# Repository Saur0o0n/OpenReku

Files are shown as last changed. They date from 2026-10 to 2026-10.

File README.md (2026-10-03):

<picture>
  <source media="(prefers-color-scheme: dark)" srcset=".github/images/openreku-logo-white.svg">
  OpenReku
</picture>

Otwarty projekt sterownika rekuperatora opartego na ESP32 i ESPHome, współpracującego z Home Assistant. Obejmuje elektronikę sterownika oraz konfigurację obsługującą wentylatory, zawory i czujniki.

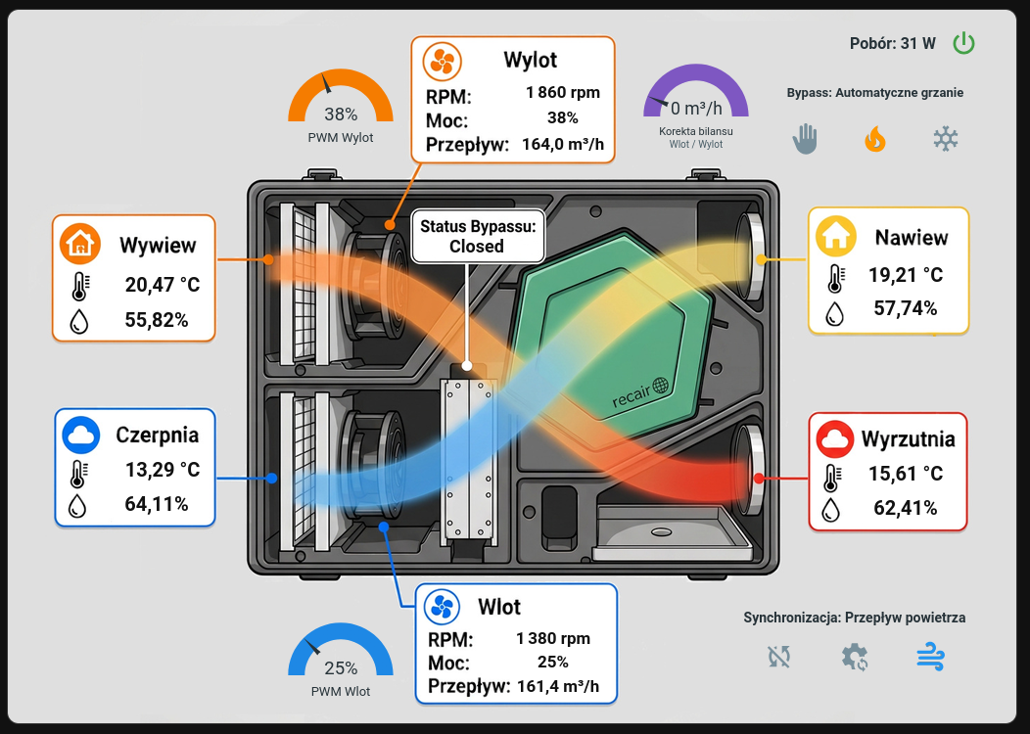
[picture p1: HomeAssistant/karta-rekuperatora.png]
OpenReku — sterowanie rekuperatorem w Home Assistant


## Zawartość repozytorium

| Katalog | Zawartość |
| --- | --- |
| [PCB/](PCB/) | Projekt płytki w wersji 1.1: schematy i PCB KiCad, lokalne biblioteki, lista elementów BOM, Gerbery do produkcji. |
| [ESPHome/](ESPHome/) | Konfiguracja `rekuperator.yaml` z obsługą urządzenia i integracją z Home Assistant oraz wzór `secrets.yaml.example` do uzupełnienia własnymi danymi dostępowymi. |
| [HomeAssistant/](HomeAssistant/) | Karta panelu Home Assistant, automatyzacje testu filtrów i korekty bilansu oraz podkład graficzny karty. |

Opis plików i instrukcję otwarcia projektu elektroniki zawiera [PCB/README.md](PCB/README.md). Przygotowanie konfiguracji i pliku sekretów opisano w [ESPHome/README.md](ESPHome/README.md). Sposób dodania karty do panelu opisano w [HomeAssistant/README.md](HomeAssistant/README.md).

## Licencja

Projekt PCB, dokumentacja i własne grafiki są udostępnione na licencji [CC BY-NC 4.0](LICENSES/CC-BY-NC-4.0.txt), a kod i konfiguracje YAML ESPHome oraz Home Assistant — na [PolyForm Noncommercial 1.0.0](LICENSES/PolyForm-Noncommercial-1.0.0.txt).

Możesz je kopiować, modyfikować i udostępniać do celów niekomercyjnych, na warunkach odpowiedniej licencji. Przy udostępnianiu zachowaj informację o autorze **Sauron**, nazwie **OpenReku**, [źródle projektu](https://github.com/Saur0o0n/OpenReku) i licencji; dla materiałów CC BY-NC oznacz również wprowadzone zmiany. Kod zawiera obowiązkową informację `Required Notice:`.

Zakres licencji i wyłączenia dotyczące cudzych materiałów określa [LICENSE](LICENSE). Wykorzystanie komercyjne wykraczające poza udzielone licencje wymaga osobnej zgody właścicieli praw.

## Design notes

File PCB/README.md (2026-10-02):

# OpenReku — PCB 1.1

Projekt płytki sterownika rekuperatora OpenReku, rewizja **1.1 z 2026-10-01**. Ten katalog zawiera źródła KiCada, lokalne biblioteki, listę elementów i archiwum produkcyjne PCB. Oprogramowanie ESPHome i pozostałe komponenty projektu należą do osobnych katalogów repozytorium.

## Wizualizacja PCB

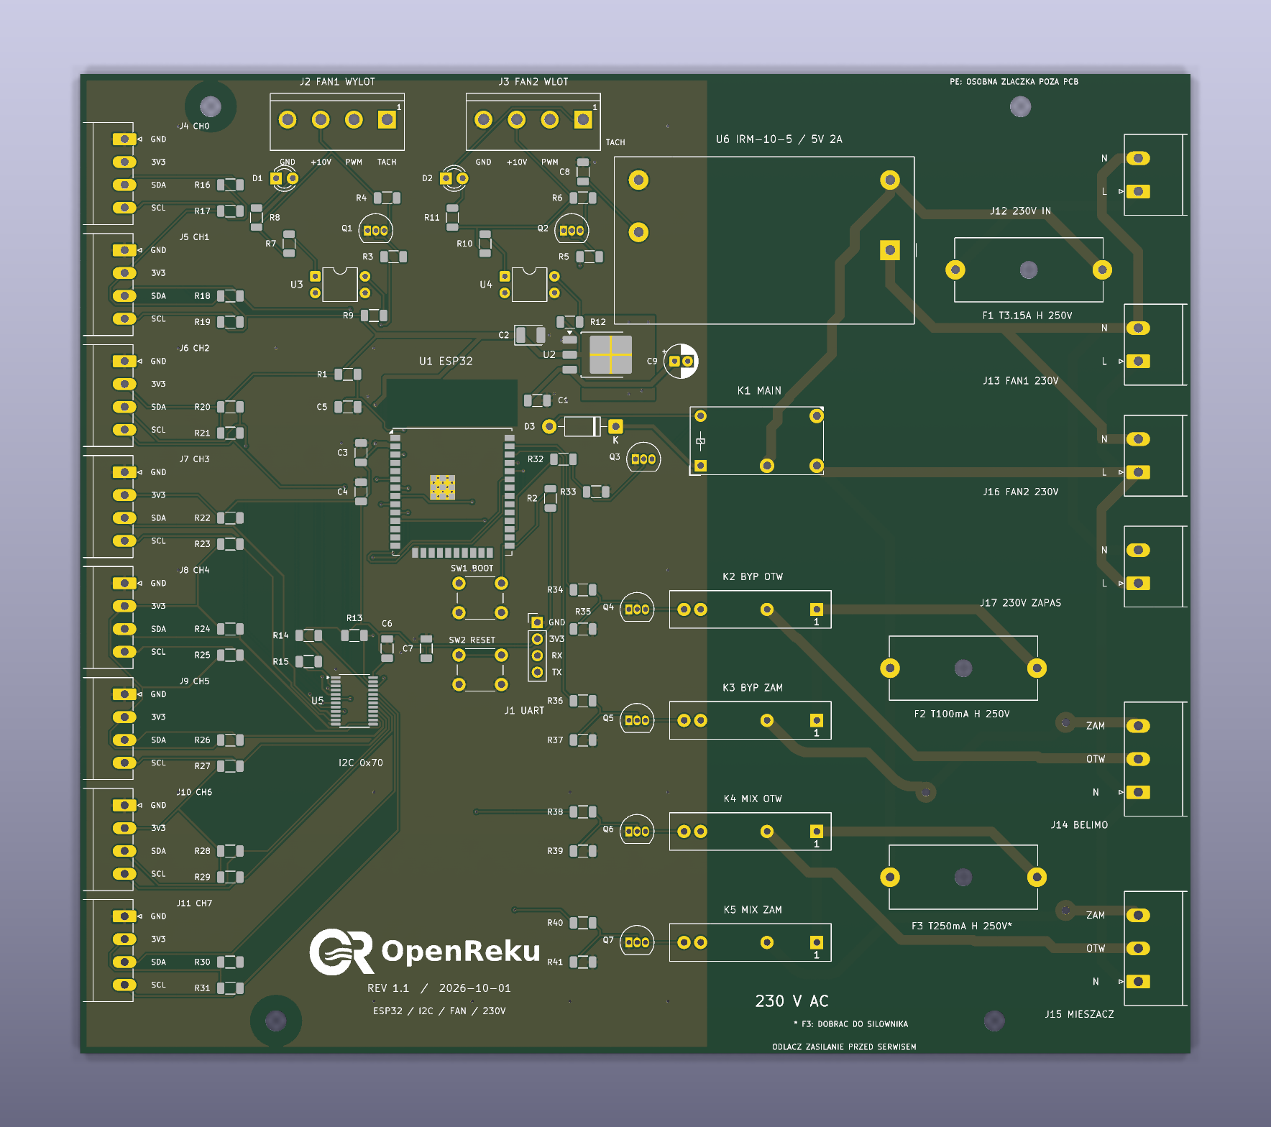
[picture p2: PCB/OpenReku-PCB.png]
OpenReku PCB 1.1 — widok płytki od góry


## Otwieranie projektu

Otwórz [OpenReku.kicad_pro](OpenReku.kicad_pro) w **KiCad 10**. Potrzebne są standardowe biblioteki symboli, footprintów i — do podglądu 3D — modeli KiCad 10.

Zachowaj razem wszystkie pliki z tego katalogu i podkatalog `Rekuperator.pretty`. KiCad odnajduje lokalne biblioteki względem katalogu, w którym znajduje się `OpenReku.kicad_pro`. Dzięki temu projekt można sklonować do dowolnego miejsca na komputerze.

Tabele `fp-lib-table` i `sym-lib-table` korzystają ze zmiennej `${KIPRJMOD}`, którą KiCad rozwija do katalogu projektu.

Lokalne biblioteki mają nazwę `Rekuperator`, używaną w odwołaniach schematu i PCB.

## Zawartość katalogu

| Plik lub katalog | Typ i przeznaczenie |
| --- | --- |
| [OpenReku.kicad_pro](OpenReku.kicad_pro) | Projekt KiCad: wspólne ustawienia schematu i PCB, klasy sieci oraz konfiguracja kontroli projektu. Główny plik do otwarcia. |
| [OpenReku.kicad_sch](OpenReku.kicad_sch) | Główny schemat KiCad: mikrokontroler, zasilanie części logicznej, interfejsy wentylatorów i odwołania do arkuszy podrzędnych. |
| [I2C.kicad_sch](I2C.kicad_sch) | Podrzędny arkusz schematu: multiplekser I²C i złącza czujników. Otwieraj w kontekście głównego projektu. |
| [230V.kicad_sch](230V.kicad_sch) | Podrzędny arkusz schematu: zasilanie sieciowe, zabezpieczenia, przekaźniki i wyjścia 230 V. |
| [OpenReku.kicad_pcb](OpenReku.kicad_pcb) | Projekt PCB KiCad: obrys płytki, rozmieszczenie elementów, ścieżki, przelotki, wylewki miedzi i nadruki. |
| [OpenReku.kicad_dru](OpenReku.kicad_dru) | Własne reguły DRC KiCada, w tym wymagane odstępy między częścią sieciową i niskonapięciową. |
| [Rekuperator.kicad_sym](Rekuperator.kicad_sym) | Lokalna biblioteka symboli schematowych KiCad; zawiera symbol przekaźnika SSR G3MB-202P. |
| [sym-lib-table](sym-lib-table) | Tabela bibliotek symboli projektu: rejestruje lokalną bibliotekę `Rekuperator.kicad_sym`. |
| [Rekuperator.pretty/](Rekuperator.pretty/) | Lokalna biblioteka footprintów KiCad. Każdy plik `.kicad_mod` opisuje pola lutownicze, obrysy lub grafikę jednego footprintu. Szczegóły poniżej. |
| [fp-lib-table](fp-lib-table) | Tabela bibliotek footprintów projektu: rejestruje katalog `Rekuperator.pretty`. |
| [BOM.csv](BOM.csv) | Lista elementów wersji 1.1, wyeksportowana z całej hierarchii schematu. Format CSV UTF-8, separator przecinek. |
| [OpenReku-v1.1-Gerber.zip](OpenReku-v1.1-Gerber.zip) | Archiwum do wykonania samej PCB: Gerbery obu warstw miedzi, obu soldermasek, górnego nadruku i obrysu, wiercenia PTH/NPTH oraz opis zadania `.gbrjob`. Nie zawiera plików automatycznego montażu. |

### Lokalna biblioteka footprintów

Poniższe pliki znajdują się w `Rekuperator.pretty/`:

| Plik `.kicad_mod` | Przeznaczenie |
| --- | --- |
| `ESP32-WROOM-32U_0.3mm_ThermalDrills.kicad_mod` | Footprint modułu ESP32-WROOM-32U z otworami termicznymi 0,3 mm. |
| `KLS2-EDV-5.08-04P-4_Vertical.kicad_mod` | Czteropinowe złącze interfejsu wentylatora, raster 5,08 mm. |
| `Omron_G3MB-202P_SIP4.kicad_mod` | Footprint przekaźnika SSR Omron G3MB-202P. |
| `PhoenixContact_MC_1,5_4-G-3.5_1x04_P3.50mm_Horizontal_Edge.kicad_mod` | Kątowe, czteropinowe złącze I²C, raster 3,50 mm, z obrysem dopasowanym do montażu przy krawędzi. |
| `PhoenixContact_MSTBA_2,5_2-G-5,08_1x02_P5.08mm_Horizontal_Edge.kicad_mod` | Kątowe, dwupinowe złącze 230 V, raster 5,08 mm, montowane przy krawędzi. |
| `PhoenixContact_MSTBA_2,5_3-G-5,08_1x03_P5.08mm_Horizontal_Edge.kicad_mod` | Kątowe, trzypinowe złącze 230 V, raster 5,08 mm, montowane przy krawędzi. |
| `Logo_OpenReku_36mm.kicad_mod` | Logo OR + OpenReku o szerokości 36 mm na górnej warstwie nadruku; nie jest elementem do zakupu. |

## BOM — lista elementów

`BOM.csv` zawiera **47 grup i 93 elementy**. Grupowanie uwzględnia wartość, footprint, numer części oraz pozostałe eksportowane właściwości, dzięki czemu elementy z odmiennymi uwagami montażowymi pozostają osobnymi pozycjami.

| Kolumna | Znaczenie |
| --- | --- |
| `Reference` | Oznaczenia elementów na schemacie i PCB, np. `R1,R2`. |
| `Quantity` | Liczba elementów w grupie. |
| `Value` | Wartość lub nazwa elementu ze schematu. |
| `Footprint` | Identyfikator biblioteki i footprintu KiCad. |
| `MPN` | Numer części producenta, jeżeli uzupełniono go w schemacie. |
| `MatingConnector` | Opis współpracującego wtyku; wtyk nie jest dodatkowo doliczony do `Quantity`. |
| `Pinout` | Opis wyprowadzeń zapisany w schemacie. |
| `AssemblyNote` | Uwagi montażowe, w tym warunki pominięcia rezystorów podciągających. |
| `DNP` | Oznaczenie elementu przewidzianego do pominięcia przy montażu, jeżeli ustawiono je w KiCadzie. |
| `Datasheet` | Odnośnik do dokumentacji części zapisany w schemacie. |

Puste pole oznacza brak informacji w schemacie. BOM nie obejmuje otworów montażowych H1–H4 ani logo LOGO1. Jest listą elementów projektu; współpracujące wtyki, przewody i osprzęt mechaniczny należy zestawić osobno.

Aby odtworzyć BOM, uruchom w tym katalogu:

```sh
kicad-cli sch export bom \
  --output BOM.csv \
  --fields 'Reference,QUANTITY,Value,Footprint,MPN,MatingConnector,Pinout,AssemblyNote,DNP,Datasheet' \
  --labels 'Reference,Quantity,Value,Footprint,MPN,MatingConnector,Pinout,AssemblyNote,DNP,Datasheet' \
  --group-by 'Value,Footprint,MPN,MatingConnector,Pinout,AssemblyNote,DNP,Datasheet' \
  --sort-field Reference \
  --ref-range-delimiter '' \
  OpenReku.kicad_sch
```

## Rewizja 1.1 względem 1.0

- Obrys PCB zmniejszono z 210 × 180 mm do **170 × 150 mm**.
- Rezystory R1–R41 i kondensatory ceramiczne C1/C3/C4/C5/C6/C7/C8 mają obudowy **1206**. C2 pozostaje tantalowy, a C9 przewlekany.
- Złącza I²C J4–J11 przesunięto o 2 mm w stronę krawędzi, zachowując raster 3,50 mm.
- Złącza 230 V J12–J17 zmieniono z rastra 7,62 mm na **5,08 mm**.
- Przeniesiono C5 i zarezerwowano miejsce dla dłuższego modułu ESP-32S 18 × 25,5 mm. Projekt elektryczny nadal wskazuje ESP32-WROOM-32U; zgodność innego modułu wymaga sprawdzenia jego padów i sposobu podłączenia anteny.
- Zmieniono rozmieszczenie i routing oraz dodano logo OR + OpenReku na górnym nadruku.

Źródła i Gerbery wersji **1.0** są dostępne w historii Git, w commicie `764cad7`. Bieżący katalog zawiera rewizję **1.1**.

## Produkcja PCB

Pliki do wykonania płytki znajdują się w [OpenReku-v1.1-Gerber.zip](OpenReku-v1.1-Gerber.zip). Parametry zamówienia:

- wymiary: **170 × 150 mm**;
- **2 warstwy**, laminat **FR-4 1,6 mm**;
- miedź **35 µm / 1 oz**;
- soldermaska obustronna, nadruk na górze.

Po zmianie projektu PCB należy ponownie wygenerować Gerbery i pliki wierceń.

Reguły DRC określają odstępy 8 mm między częścią sieciową i niskonapięciową oraz 3 mm między różnymi sieciami części sieciowej.

Pliki lokalnych ustawień `*.kicad_prl`, blokady `*.lck`, autosave, kopie zapasowe i cache footprintów są pomijane przez główny [`.gitignore`](../.gitignore). Nie są potrzebne do odtworzenia projektu.

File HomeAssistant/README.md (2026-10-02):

# OpenReku — karta Home Assistant

Karta `picture-elements` z odczytami temperatury i wilgotności, obrotami i przepływem wentylatorów, wskaźnikami PWM oraz sterowaniem bypassem i synchronizacją wentylatorów.

## Pliki

| Plik | Przeznaczenie |
| --- | --- |
| [karta_rekuperator.yaml](karta_rekuperator.yaml) | Konfiguracja karty do wklejenia w edytorze YAML panelu Home Assistant. |
| [automations/test_filtrow.yaml](automations/test_filtrow.yaml) | Automatyzacja uruchamiająca codzienny test filtrów o 03:30. |
| [automations/korekta_bilansu_wyciag.yaml](automations/korekta_bilansu_wyciag.yaml) | Korekta bilansu nawiew/wywiew zależna od stanu wyciągu kuchennego. |
| [www/rekuperator2.jpg](www/rekuperator2.jpg) | Podkład graficzny karty z ilustracją rekuperatora i polami na odczyty. |

## Przykład

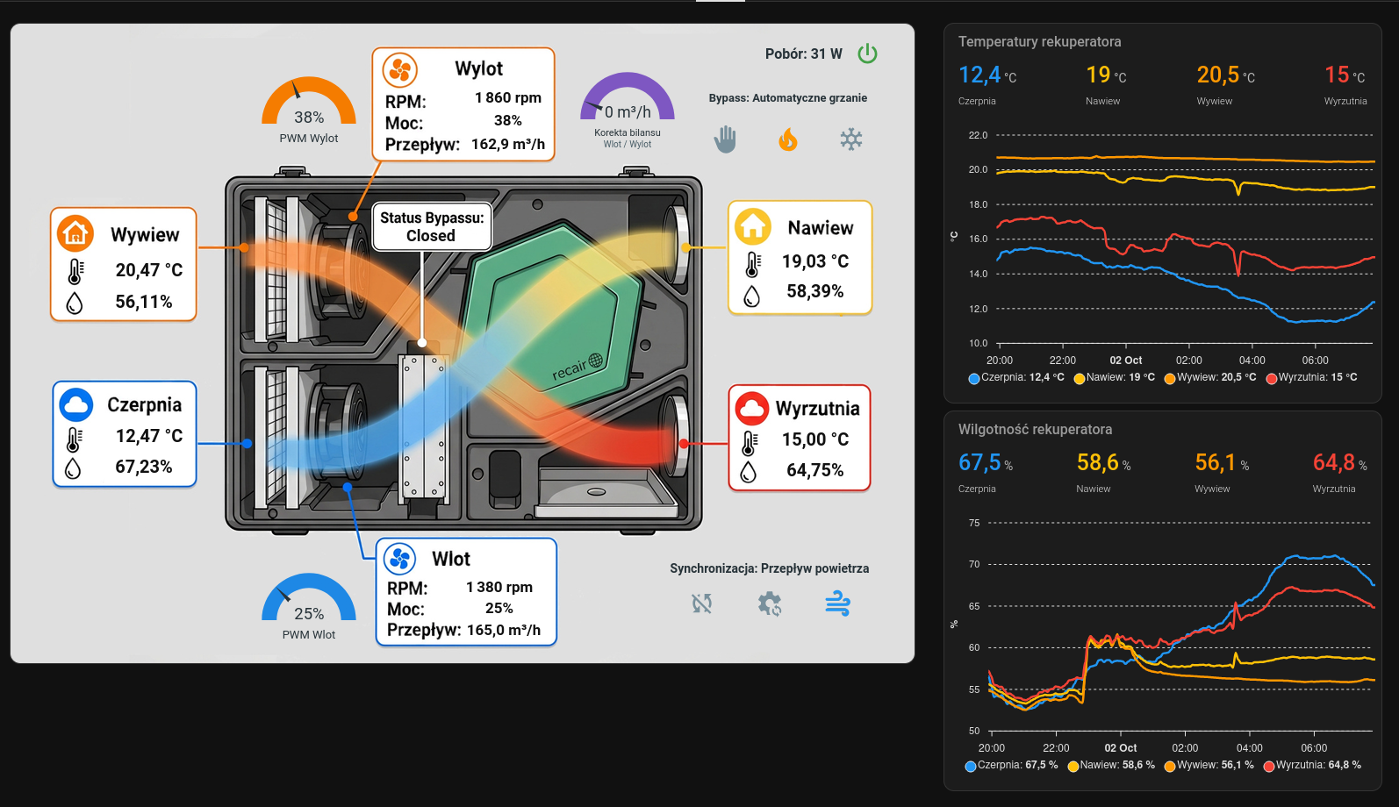
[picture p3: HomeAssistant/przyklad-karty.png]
Karta rekuperatora w Home Assistant


YAML zawiera kartę z ilustracją po lewej stronie. Wykresy temperatur i wilgotności widoczne po prawej są osobnymi kartami panelu.

## Instalacja

1. Dodaj urządzenie ESPHome do Home Assistant, aby udostępnić jego encje.
2. Zainstaluj dodatki [hui-element](https://github.com/thomasloven/lovelace-hui-element) i [Gauge Card Pro](https://github.com/benjamin-dcs/gauge-card-pro), np. przez HACS, zgodnie z ich instrukcjami. Karta używa `custom:hui-element` do osadzania wskaźników `custom:gauge-card-pro` i komunikatu trybu serwisowego.
3. Skopiuj `www/rekuperator2.jpg` do katalogu `www` konfiguracji Home Assistant, zwykle `/config/www/rekuperator2.jpg`. W YAML odpowiada mu ścieżka `image: /local/rekuperator2.jpg`. Jeśli tworzysz katalog `www` po raz pierwszy, uruchom ponownie Home Assistant. [Opis obsługi plików lokalnych](https://www.home-assistant.io/integrations/http/#hosting-files).
4. W edycji panelu dodaj kartę ręczną i wklej zawartość `karta_rekuperator.yaml`.
5. Dopasuj identyfikatory encji do swojej instalacji. Plik używa nazw z prefiksem `kotlownia_rekuperator_`; mogą się one różnić od nazw utworzonych przez Twoją integrację ESPHome.

## Test filtrów

W edytorze automatyzacji Home Assistant utwórz nową automatyzację i wklej w trybie YAML zawartość [test_filtrow.yaml](automations/test_filtrow.yaml). Godzina `03:30:00` odnosi się do strefy czasowej Home Assistanta.

Automatyzacja wywołuje `esphome.rekuperator_run_filter_test`. Jeśli urządzenie ma inną nazwę, wybierz odpowiadającą mu akcję `run_filter_test`. Procedurę pomiarową wykonuje ESPHome.

## Wyciąg kuchenny

Wklej [korekta_bilansu_wyciag.yaml](automations/korekta_bilansu_wyciag.yaml) jako osobną automatyzację w edytorze YAML. Ustawia korektę bilansu na `30` przy włączonym wyciągu i na `0` przy wyłączonym.

Dopasuj encję wyciągu `switch.shelly1pm3_wentylator_switch_0` oraz encję korekty `number.kotlownia_rekuperator_korekta_bilansu_wlot_wylot` do swojej instalacji.

## Encje i obsługa

- Temperatury i wilgotności: czerpnia, nawiew, wywiew i wyrzutnia.
- Wentylatory: PWM, RPM i przepływ powietrza dla wlotu i wylotu.
- Synchronizacja: `Brak`, `Moc PWM` lub `Przepływ powietrza`, wraz z korektą bilansu.
- Bypass: stan zaworu oraz wybór `Ręczne sterowanie`, `Automatyczne grzanie` lub `Automatyczne chłodzenie`.
- Zasilanie i tryb serwisowy: po wyłączeniu zasilania karta jest przygaszona, a sterowanie zablokowane poza przyciskiem zasilania. Tryb serwisowy blokuje całą kartę i wyświetla komunikat.

Odczyt „Pobór” korzysta z osobnego licznika energii: `sensor.kotlownia_shellypmminig3_rekuperator_power`. Podmień tę encję na własny pomiar mocy albo usuń odpowiadający jej element `state-label`, jeśli nie używasz licznika.

Układ nakłada odczyty na konkretne miejsca podkładu. Przy zmianie grafiki zachowaj jej proporcje lub dopasuj pozycje `top` i `left` elementów.

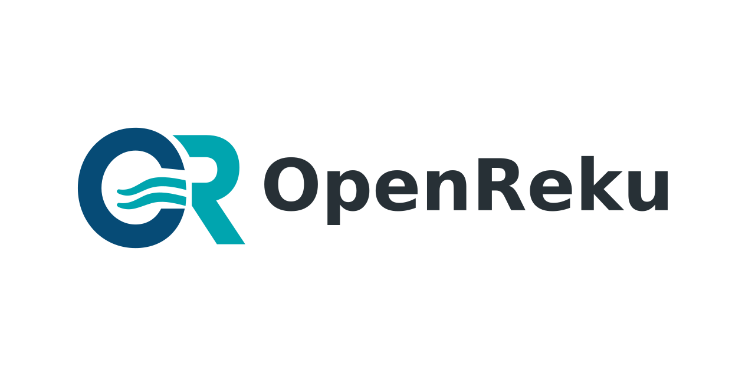
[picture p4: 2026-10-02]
.github/images/social-preview.png

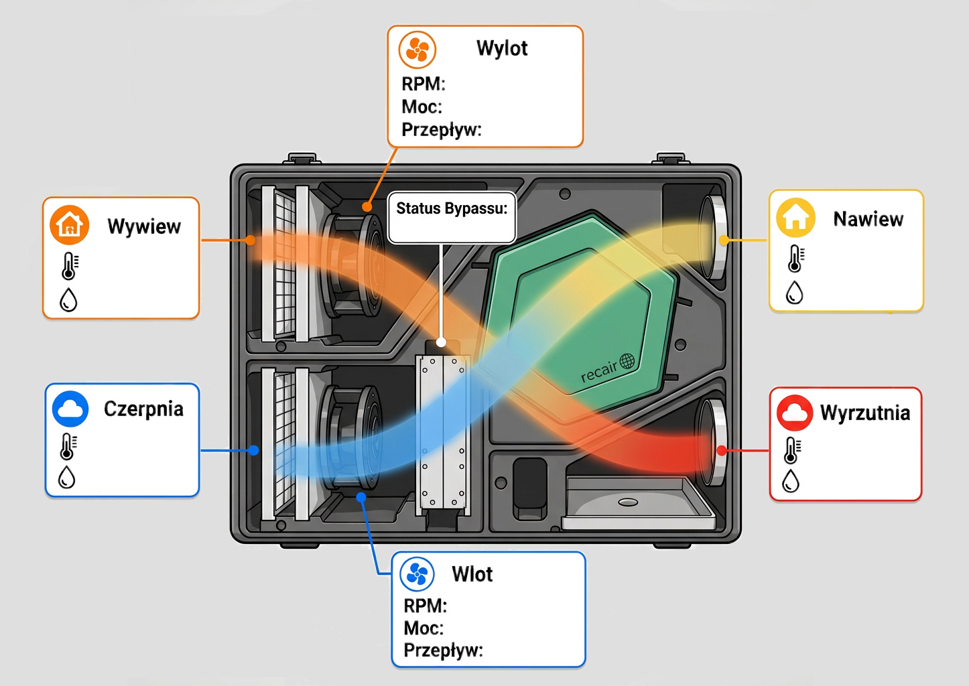
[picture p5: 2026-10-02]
HomeAssistant/www/rekuperator2.jpg

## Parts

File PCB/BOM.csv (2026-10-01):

Reference | Quantity | Value | Footprint | MPN | MatingConnector | Pinout | AssemblyNote | DNP | Datasheet
C1 | 1 | 10uF / 16V X7R | Capacitor_SMD:C_1206_3216Metric
C2 | 1 | 22uF / 10V Ta | Capacitor_Tantalum_SMD:CP_EIA-3528-21_Kemet-B
C3,C6,C8 | 3 | 100nF | Capacitor_SMD:C_1206_3216Metric
C4 | 1 | 10uF | Capacitor_SMD:C_1206_3216Metric
C5 | 1 | 1uF / 10V X7R | Capacitor_SMD:C_1206_3216Metric
C7 | 1 | 1uF | Capacitor_SMD:C_1206_3216Metric
C9 | 1 | 47uF / 16V | Capacitor_THT:CP_Radial_D5.0mm_P2.00mm
D1,D2 | 2 | LED RPM | LED_THT:LED_D3.0mm
D3 | 1 | 1N4007 | Diode_THT:D_DO-41_SOD81_P10.16mm_Horizontal
F1 | 1 | T3.15A H 250V | Fuse:Fuseholder_Cylinder-5x20mm_Schurter_0031_8201_Horizontal_Open
F2 | 1 | T100mA H 250V | Fuse:Fuseholder_Cylinder-5x20mm_Schurter_0031_8201_Horizontal_Open
F3 | 1 | T250mA H 250V * | Fuse:Fuseholder_Cylinder-5x20mm_Schurter_0031_8201_Horizontal_Open
J1 | 1 | UART 3V3 | Connector_PinHeader_2.54mm:PinHeader_1x04_P2.54mm_Vertical
J2 | 1 | FAN1 WYLOT | Rekuperator:KLS2-EDV-5.08-04P-4_Vertical | KLS2-EDV-5.08-04P-4 | KLS2-EDK-5.08-04P-4S |  |  |  | https://img.klsele.com/admin/product_upload/20250331141523L-KLS2-EDV-5.00%265.08.pdf
J3 | 1 | FAN2 WLOT | Rekuperator:KLS2-EDV-5.08-04P-4_Vertical | KLS2-EDV-5.08-04P-4 | KLS2-EDK-5.08-04P-4S |  |  |  | https://img.klsele.com/admin/product_upload/20250331141523L-KLS2-EDV-5.00%265.08.pdf
J4 | 1 | CH0 ARK 3.5 | Rekuperator:PhoenixContact_MC_1,5_4-G-3.5_1x04_P3.50mm_Horizontal_Edge | 1844236 | Phoenix Contact 1840382 / MC 1,5/4-ST-3,5 | 1 GND; 2 +3V3; 3 SDA; 4 SCL
J5 | 1 | CH1 ARK 3.5 | Rekuperator:PhoenixContact_MC_1,5_4-G-3.5_1x04_P3.50mm_Horizontal_Edge | 1844236 | Phoenix Contact 1840382 / MC 1,5/4-ST-3,5 | 1 GND; 2 +3V3; 3 SDA; 4 SCL
J6 | 1 | CH2 ARK 3.5 | Rekuperator:PhoenixContact_MC_1,5_4-G-3.5_1x04_P3.50mm_Horizontal_Edge | 1844236 | Phoenix Contact 1840382 / MC 1,5/4-ST-3,5 | 1 GND; 2 +3V3; 3 SDA; 4 SCL
J7 | 1 | CH3 ARK 3.5 | Rekuperator:PhoenixContact_MC_1,5_4-G-3.5_1x04_P3.50mm_Horizontal_Edge | 1844236 | Phoenix Contact 1840382 / MC 1,5/4-ST-3,5 | 1 GND; 2 +3V3; 3 SDA; 4 SCL
J8 | 1 | CH4 ARK 3.5 | Rekuperator:PhoenixContact_MC_1,5_4-G-3.5_1x04_P3.50mm_Horizontal_Edge | 1844236 | Phoenix Contact 1840382 / MC 1,5/4-ST-3,5 | 1 GND; 2 +3V3; 3 SDA; 4 SCL
J9 | 1 | CH5 ARK 3.5 | Rekuperator:PhoenixContact_MC_1,5_4-G-3.5_1x04_P3.50mm_Horizontal_Edge | 1844236 | Phoenix Contact 1840382 / MC 1,5/4-ST-3,5 | 1 GND; 2 +3V3; 3 SDA; 4 SCL
J10 | 1 | CH6 ARK 3.5 | Rekuperator:PhoenixContact_MC_1,5_4-G-3.5_1x04_P3.50mm_Horizontal_Edge | 1844236 | Phoenix Contact 1840382 / MC 1,5/4-ST-3,5 | 1 GND; 2 +3V3; 3 SDA; 4 SCL
J11 | 1 | CH7 ARK 3.5 | Rekuperator:PhoenixContact_MC_1,5_4-G-3.5_1x04_P3.50mm_Horizontal_Edge | 1844236 | Phoenix Contact 1840382 / MC 1,5/4-ST-3,5 | 1 GND; 2 +3V3; 3 SDA; 4 SCL
J12 | 1 | 230V IN | Rekuperator:PhoenixContact_MSTBA_2,5_2-G-5,08_1x02_P5.08mm_Horizontal_Edge | 1757242 | MSTB 2,5/2-ST-5,08 | 1 MAINS_L_IN; 2 MAINS_N
J13 | 1 | REKU FAN 1 | Rekuperator:PhoenixContact_MSTBA_2,5_2-G-5,08_1x02_P5.08mm_Horizontal_Edge | 1757242 | MSTB 2,5/2-ST-5,08 | 1 MAINS_L_REKU; 2 MAINS_N
J14 | 1 | BELIMO | Rekuperator:PhoenixContact_MSTBA_2,5_3-G-5,08_1x03_P5.08mm_Horizontal_Edge | 1757255 | MSTB 2,5/3-ST-5,08 | 1 MAINS_N; 2 MAINS_BYPASS_OPEN; 3 MAINS_BYPASS_CLOSE
J15 | 1 | MIX 230V | Rekuperator:PhoenixContact_MSTBA_2,5_3-G-5,08_1x03_P5.08mm_Horizontal_Edge | 1757255 | MSTB 2,5/3-ST-5,08 | 1 MAINS_N; 2 MAINS_MIX_OPEN; 3 MAINS_MIX_CLOSE
J16 | 1 | REKU FAN 2 | Rekuperator:PhoenixContact_MSTBA_2,5_2-G-5,08_1x02_P5.08mm_Horizontal_Edge | 1757242 | MSTB 2,5/2-ST-5,08 | 1 MAINS_L_REKU; 2 MAINS_N
J17 | 1 | REKU ZAPAS | Rekuperator:PhoenixContact_MSTBA_2,5_2-G-5,08_1x02_P5.08mm_Horizontal_Edge | 1757242 | MSTB 2,5/2-ST-5,08 | 1 MAINS_L_REKU; 2 MAINS_N
K1 | 1 | Finder 32.21 / 5V | Relay_THT:Relay_SPDT_Finder_32.21-x000 | 32.21.7.005.4000 |  |  | 6 A AC1; verify recuperator inrush and load category before production
K2,K3,K4,K5 | 4 | G3MB-202P DC5 | Rekuperator:Omron_G3MB-202P_SIP4 | G3MB-202P DC5 |  |  | Legacy tested prototype circuit; load current below 100mA is outside manufacturer specification |  | https://components101.com/sites/default/files/component_datasheet/G3MB-202P-Datasheet.pdf
Q1,Q2,Q3,Q4,Q5,Q6,Q7 | 7 | 2N3904 | Package_TO_SOT_THT:TO-92_Inline
R1,R2,R4,R6,R15 | 5 | 10k | Resistor_SMD:R_1206_3216Metric
R3,R5 | 2 | 2.2k | Resistor_SMD:R_1206_3216Metric
R7,R10 | 2 | 1.8k | Resistor_SMD:R_1206_3216Metric
R8,R9,R11,R12,R13,R14 | 6 | 4.7k | Resistor_SMD:R_1206_3216Metric
R16,R17,R18,R19,R20,R21,R22,R23,R24,R25,R26,R27,R28,R29,R30,R31 | 16 | 4.7k | Resistor_SMD:R_1206_3216Metric |  |  |  | Omit if sensor module already has adequate pull-up to 3.3 V
R32 | 1 | 470 | Resistor_SMD:R_1206_3216Metric
R33,R35,R37,R39,R41 | 5 | 100k | Resistor_SMD:R_1206_3216Metric
R34,R36,R38,R40 | 4 | 1k | Resistor_SMD:R_1206_3216Metric
SW1 | 1 | BOOT | Button_Switch_THT:SW_PUSH_6mm
SW2 | 1 | RESET | Button_Switch_THT:SW_PUSH_6mm
U1 | 1 | ESP32-WROOM-32U | Rekuperator:ESP32-WROOM-32U_0.3mm_ThermalDrills |  |  |  |  |  | https://www.espressif.com/sites/default/files/documentation/esp32-wroom-32d_esp32-wroom-32u_datasheet_en.pdf
U2 | 1 | LM1117DT-3.3 | Package_TO_SOT_SMD:TO-252-3_TabPin2 |  |  |  |  |  | http://www.ti.com/lit/ds/symlink/lm1117.pdf
U3,U4 | 2 | PC817 | Package_DIP:DIP-4_W7.62mm
U5 | 1 | TCA9548APWR | Package_SO:TSSOP-24_4.4x7.8mm_P0.65mm | TCA9548APWR |  |  |  |  | https://www.ti.com/lit/ds/symlink/tca9548a.pdf
U6 | 1 | IRM-10-5 | Converter_ACDC:Converter_ACDC_MeanWell_IRM-10-xx_THT

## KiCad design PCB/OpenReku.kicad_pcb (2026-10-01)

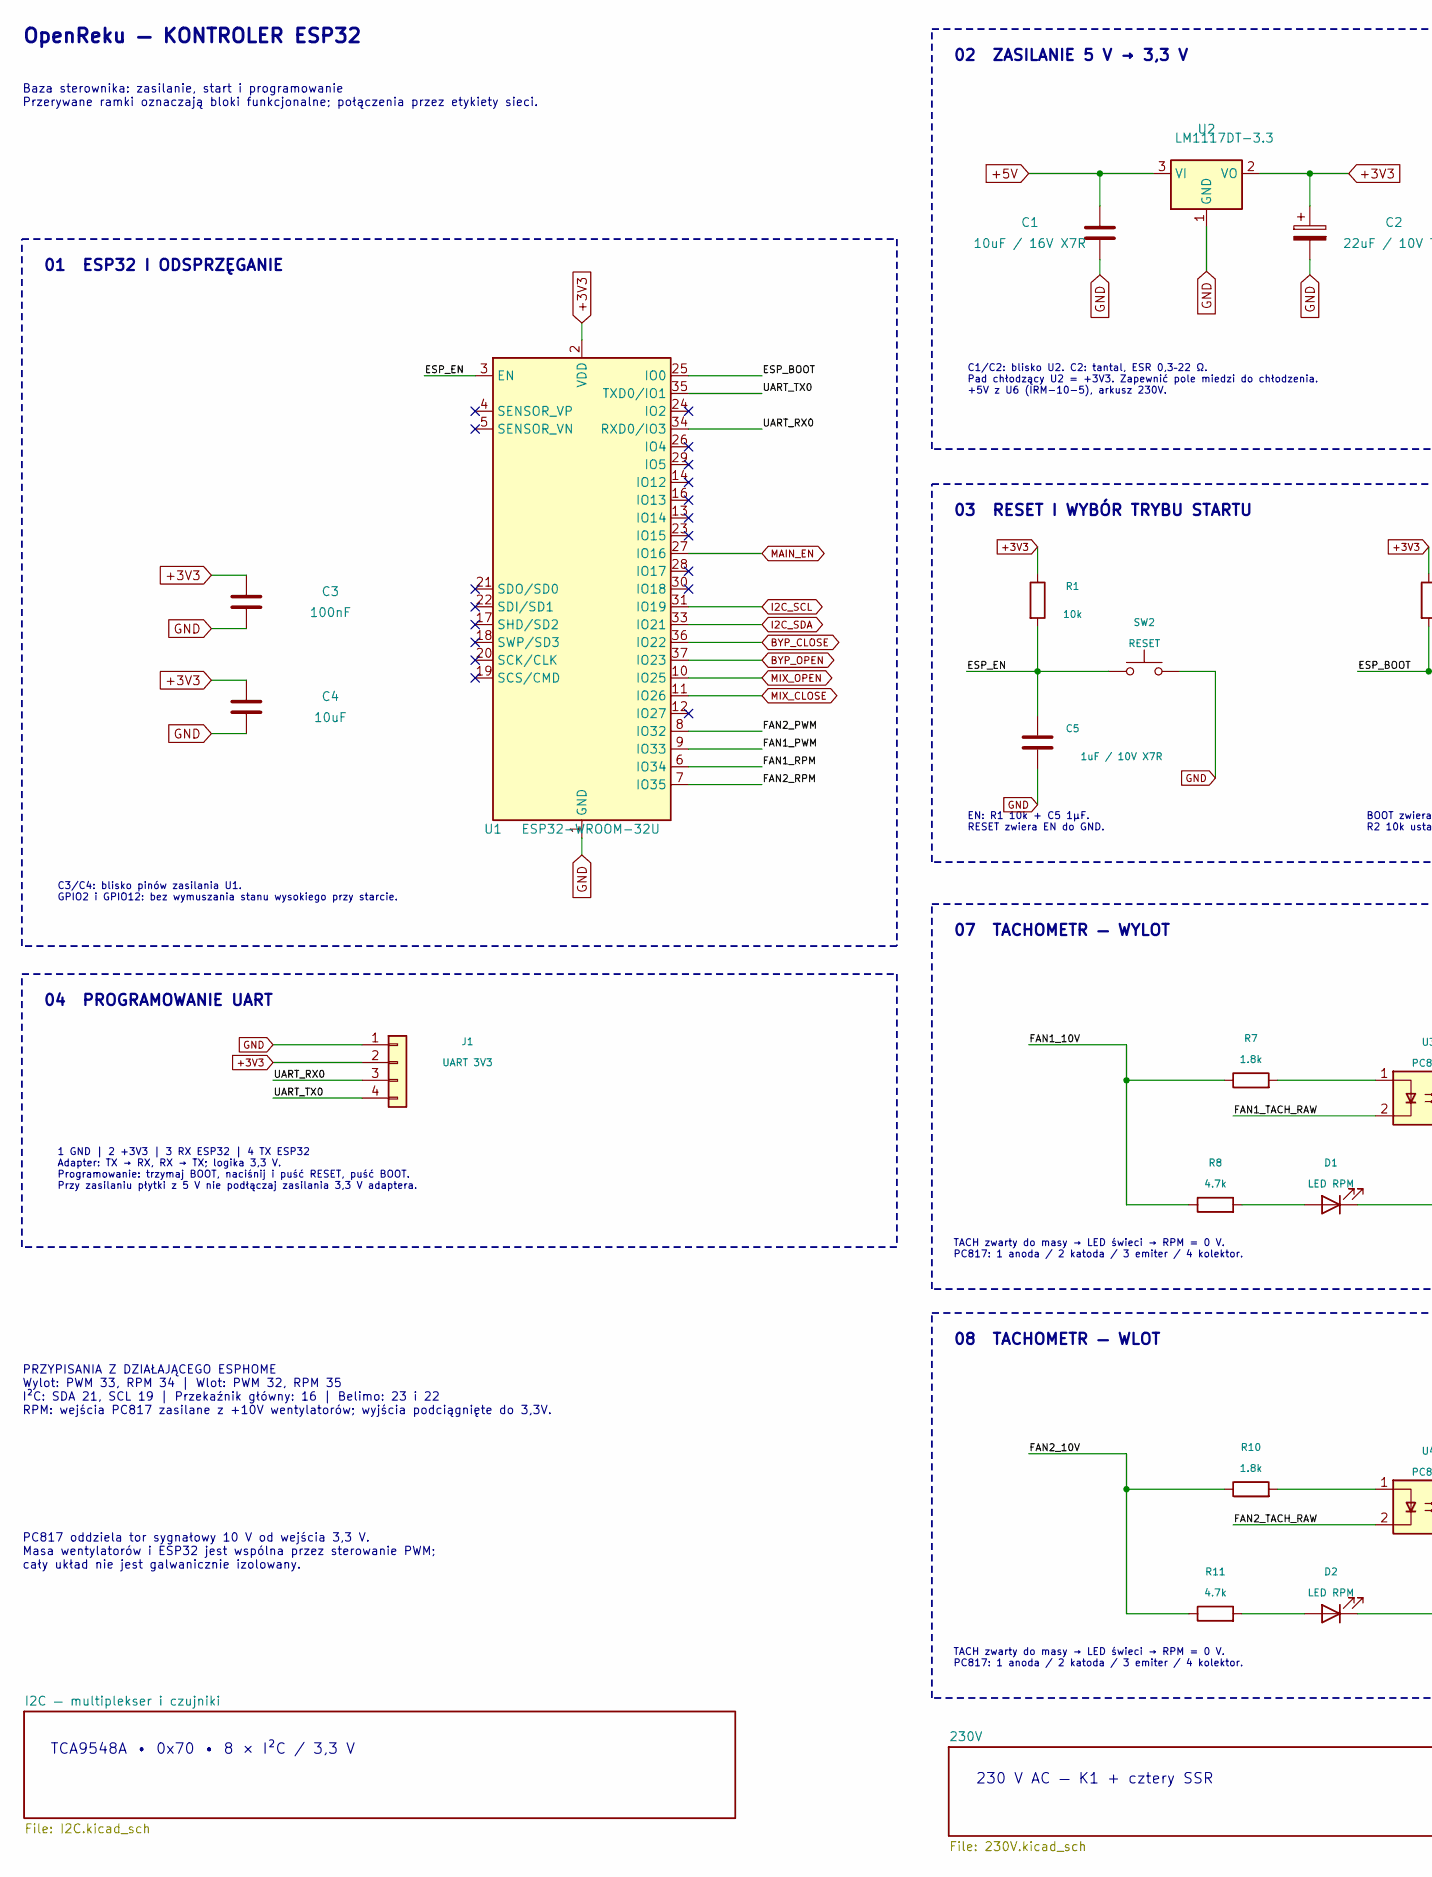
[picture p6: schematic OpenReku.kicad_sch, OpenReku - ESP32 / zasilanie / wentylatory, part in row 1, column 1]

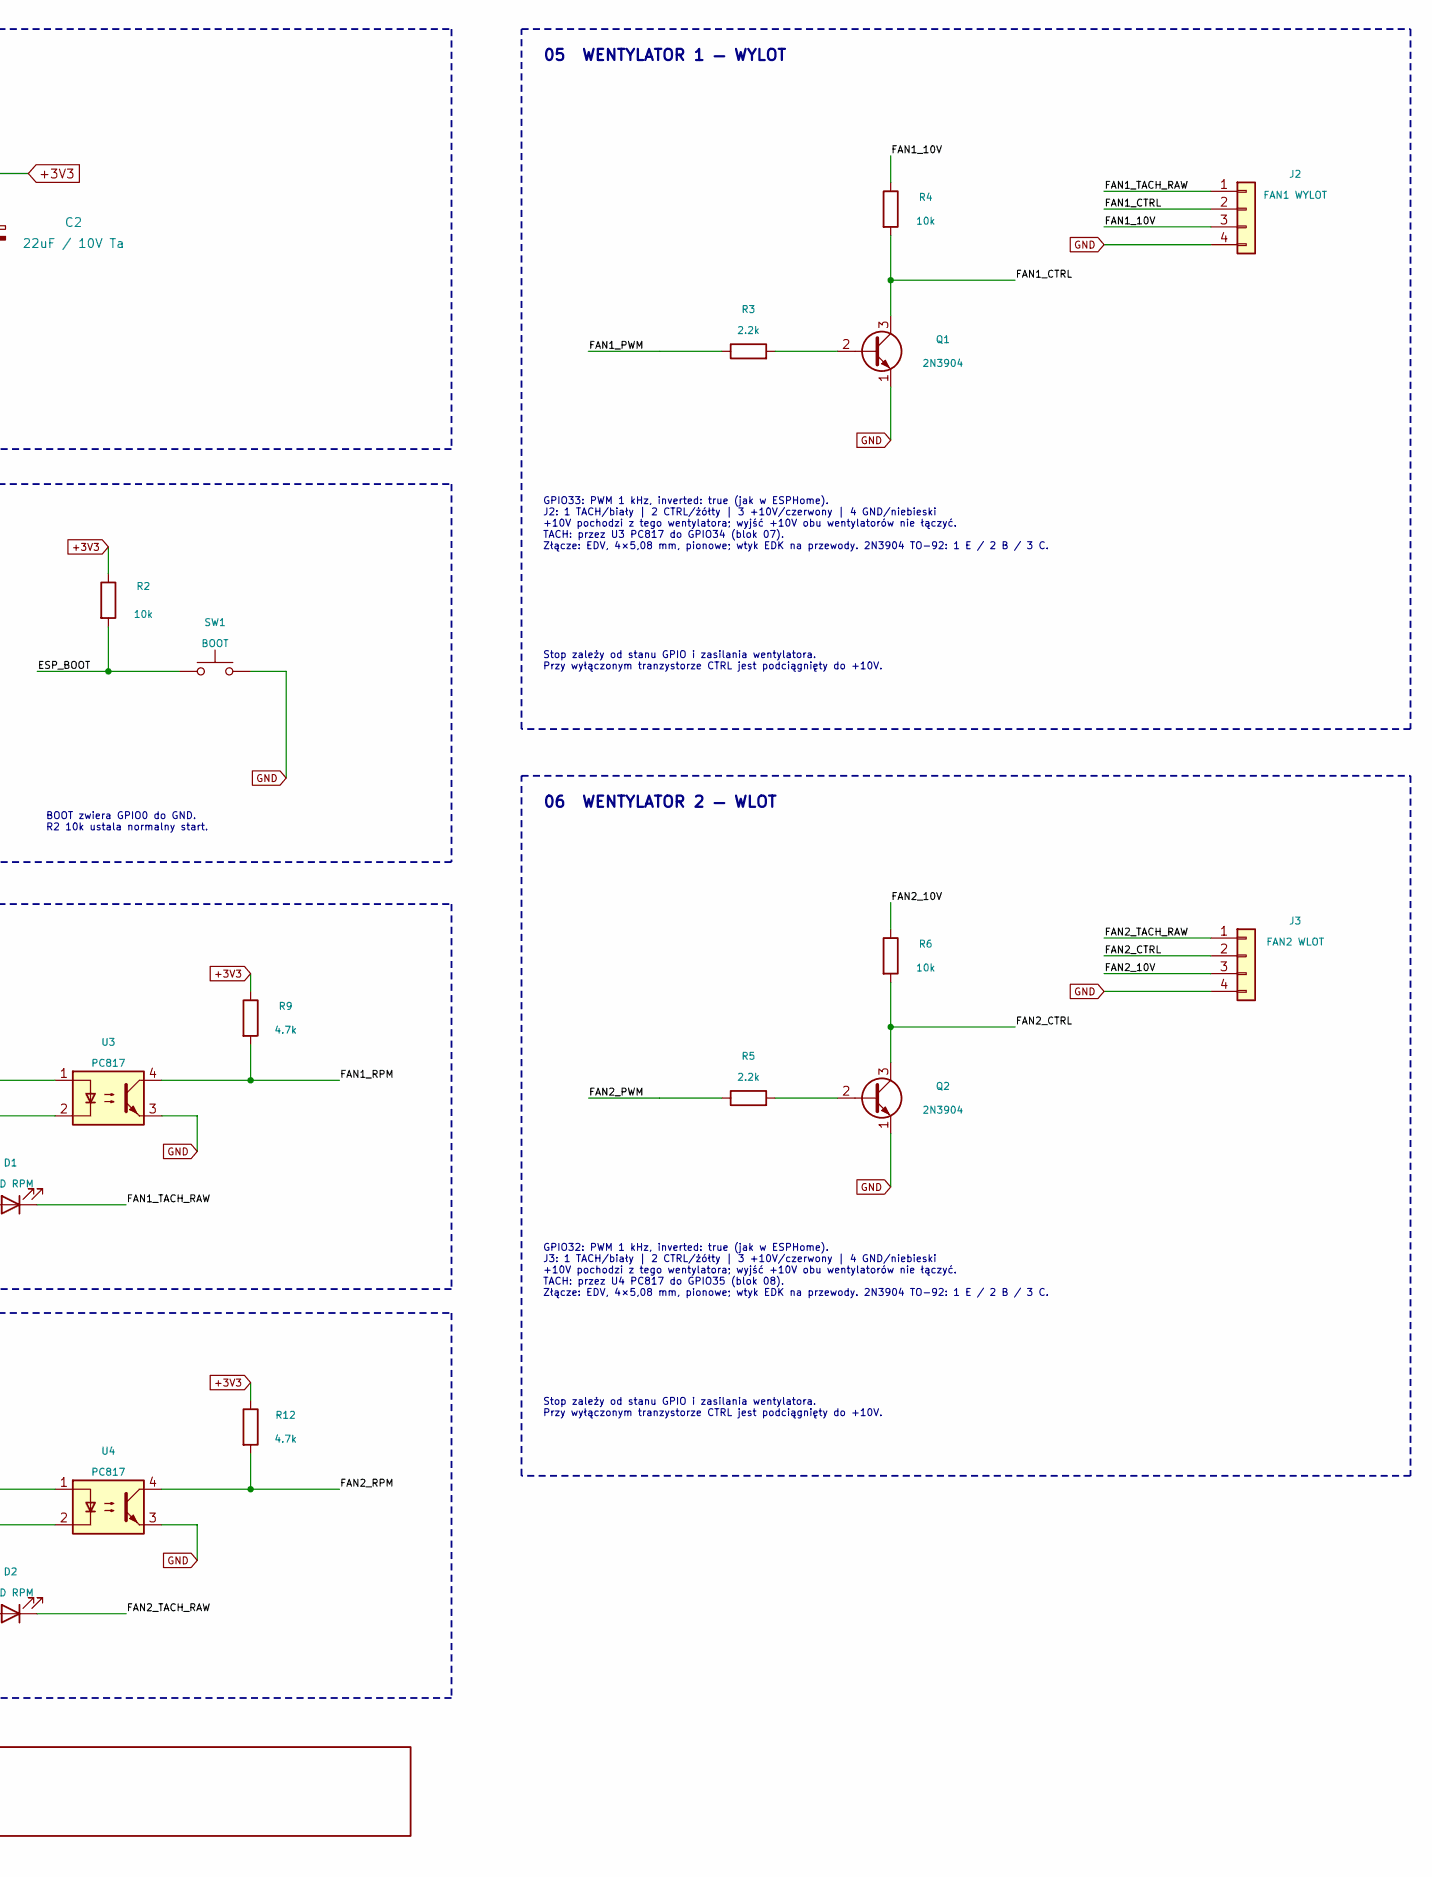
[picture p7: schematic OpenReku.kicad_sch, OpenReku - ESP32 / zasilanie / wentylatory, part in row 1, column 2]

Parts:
C1: 10uF / 16V X7R; C_1206_3216Metric
C2: 22uF / 10V Ta; CP_EIA-3528-21_Kemet-B
C3: 100nF; C_1206_3216Metric
C4: 10uF; C_1206_3216Metric
C5: 1uF / 10V X7R; C_1206_3216Metric
D1, D2: LED RPM; LED_D3.0mm
J1: UART 3V3; PinHeader_1x04_P2.54mm_Vertical
J2: FAN1 WYLOT; KLS2-EDV-5.08-04P-4_Vertical; MPN KLS2-EDV-5.08-04P-4
J3: FAN2 WLOT; KLS2-EDV-5.08-04P-4_Vertical; MPN KLS2-EDV-5.08-04P-4
Q1, Q2: 2N3904; TO-92_Inline
R1, R2, R4, R6: 10k; R_1206_3216Metric
R3, R5: 2.2k; R_1206_3216Metric
R7, R10: 1.8k; R_1206_3216Metric
R8, R9, R11, R12: 4.7k; R_1206_3216Metric
SW1: BOOT; SW_PUSH_6mm
SW2: RESET; SW_PUSH_6mm
U1: ESP32-WROOM-32U; ESP32-WROOM-32U_0.3mm_ThermalDrills
U2: LM1117DT-3.3; TO-252-3_TabPin2
U3, U4: PC817; DIP-4_W7.62mm

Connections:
+3V3: C2.1, C3.1, C4.1, J1.2, R1.1, R2.1, R9.1, R12.1, U1.2 (VDD), U2.2 (VO); also elsewhere on the board
+5V: C1.1, U2.3 (VI); also elsewhere on the board
/ESP_BOOT: R2.2, SW1.1, U1.25 (IO0)
/ESP_EN: C5.1, R1.2, SW2.1, U1.3 (EN)
/FAN1_10V: J2.3, R4.1, R7.1, R8.1
/FAN1_CTRL: J2.2, Q1.3 (C), R4.2
/FAN1_PWM: R3.1, U1.9 (IO33)
/FAN1_RPM: R9.2, U1.6 (IO34), U3.4
/FAN1_TACH_RAW: D1.1 (K), J2.1, U3.2
/FAN2_10V: J3.3, R6.1, R10.1, R11.1
/FAN2_CTRL: J3.2, Q2.3 (C), R6.2
/FAN2_PWM: R5.1, U1.8 (IO32)
/FAN2_RPM: R12.2, U1.7 (IO35), U4.4
/FAN2_TACH_RAW: D2.1 (K), J3.1, U4.2
/UART_RX0: J1.3, U1.34 (RXD0/IO3)
/UART_TX0: J1.4, U1.35 (TXD0/IO1)
BYP_CLOSE: U1.36 (IO22); also elsewhere on the board
BYP_OPEN: U1.37 (IO23); also elsewhere on the board
GND: C1.2, C2.2, C3.2, C4.2, C5.2, J1.1, J2.4, J3.4, Q1.1 (E), Q2.1 (E), SW1.2, SW2.2, U1.1 (GND), U1.15 (GND), U1.38 (GND), U1.39 (GND), U2.1 (GND), U3.3, U4.3; also elsewhere on the board
I2C_SCL: U1.31 (IO19); also elsewhere on the board
I2C_SDA: U1.33 (IO21); also elsewhere on the board
MAIN_EN: U1.27 (IO16); also elsewhere on the board
MIX_CLOSE: U1.11 (IO26); also elsewhere on the board
MIX_OPEN: U1.10 (IO25); also elsewhere on the board
unnamed: D1.2 (A), R8.2
unnamed: D2.2 (A), R11.2
unnamed: Q1.2 (B), R3.2
unnamed: Q2.2 (B), R5.2
unnamed: R7.2, U3.1
unnamed: R10.2, U4.1

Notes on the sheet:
01 ESP32 I ODSPRZĘGANIE
02 ZASILANIE 5 V → 3,3 V
03 RESET I WYBÓR TRYBU STARTU
04 PROGRAMOWANIE UART
C3/C4: blisko pinów zasilania U1. GPIO2 i GPIO12: bez wymuszania stanu wysokiego przy starcie.
C1/C2: blisko U2. C2: tantal, ESR 0,3–22 Ω. Pad chłodzący U2 = +3V3. Zapewnić pole miedzi do chłodzenia. +5V z U6 (IRM-10-5), arkusz 230V.
EN: R1 10k + C5 1µF. RESET zwiera EN do GND.
BOOT zwiera GPIO0 do GND. R2 10k ustala normalny start.
1 GND | 2 +3V3 | 3 RX ESP32 | 4 TX ESP32 Adapter: TX → RX, RX → TX; logika 3,3 V. Programowanie: trzymaj BOOT, naciśnij i puść RESET, puść BOOT. Przy zasilaniu płytki z 5 V nie podłączaj zasilania 3,3 V adaptera.
OpenReku — KONTROLER ESP32
Baza sterownika: zasilanie, start i programowanie Przerywane ramki oznaczają bloki funkcjonalne; połączenia przez etykiety sieci.
05 WENTYLATOR 1 — WYLOT
GPIO33: PWM 1 kHz, inverted: true (jak w ESPHome). J2: 1 TACH/biały | 2 CTRL/żółty | 3 +10V/czerwony | 4 GND/niebieski +10V pochodzi z tego wentylatora; wyjść +10V obu wentylatorów nie łączyć. TACH: przez U3 PC817 do GPIO34 (blok 07). Złącze: EDV, 4×5,08 mm, pionowe; wtyk EDK na przewody. 2N3904 TO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
Stop zależy od stanu GPIO i zasilania wentylatora. Przy wyłączonym tranzystorze CTRL jest podciągnięty do +10V.
06 WENTYLATOR 2 — WLOT
GPIO32: PWM 1 kHz, inverted: true (jak w ESPHome). J3: 1 TACH/biały | 2 CTRL/żółty | 3 +10V/czerwony | 4 GND/niebieski +10V pochodzi z tego wentylatora; wyjść +10V obu wentylatorów nie łączyć. TACH: przez U4 PC817 do GPIO35 (blok 08). Złącze: EDV, 4×5,08 mm, pionowe; wtyk EDK na przewody. 2N3904 TO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
PRZYPISANIA Z DZIAŁAJĄCEGO ESPHOME Wylot: PWM 33, RPM 34 | Wlot: PWM 32, RPM 35 I²C: SDA 21, SCL 19 | Przekaźnik główny: 16 | Belimo: 23 i 22 RPM: wejścia PC817 zasilane z +10V wentylatorów; wyjścia podciągnięte do 3,3V.
07 TACHOMETR — WYLOT
TACH zwarty do masy → LED świeci → RPM = 0 V. PC817: 1 anoda / 2 katoda / 3 emiter / 4 kolektor.
08 TACHOMETR — WLOT
PC817 oddziela tor sygnałowy 10 V od wejścia 3,3 V. Masa wentylatorów i ESP32 jest wspólna przez sterowanie PWM; cały układ nie jest galwanicznie izolowany.
TCA9548A • 0x70 • 8 × I²C / 3,3 V
230 V AC — K1 + cztery SSR

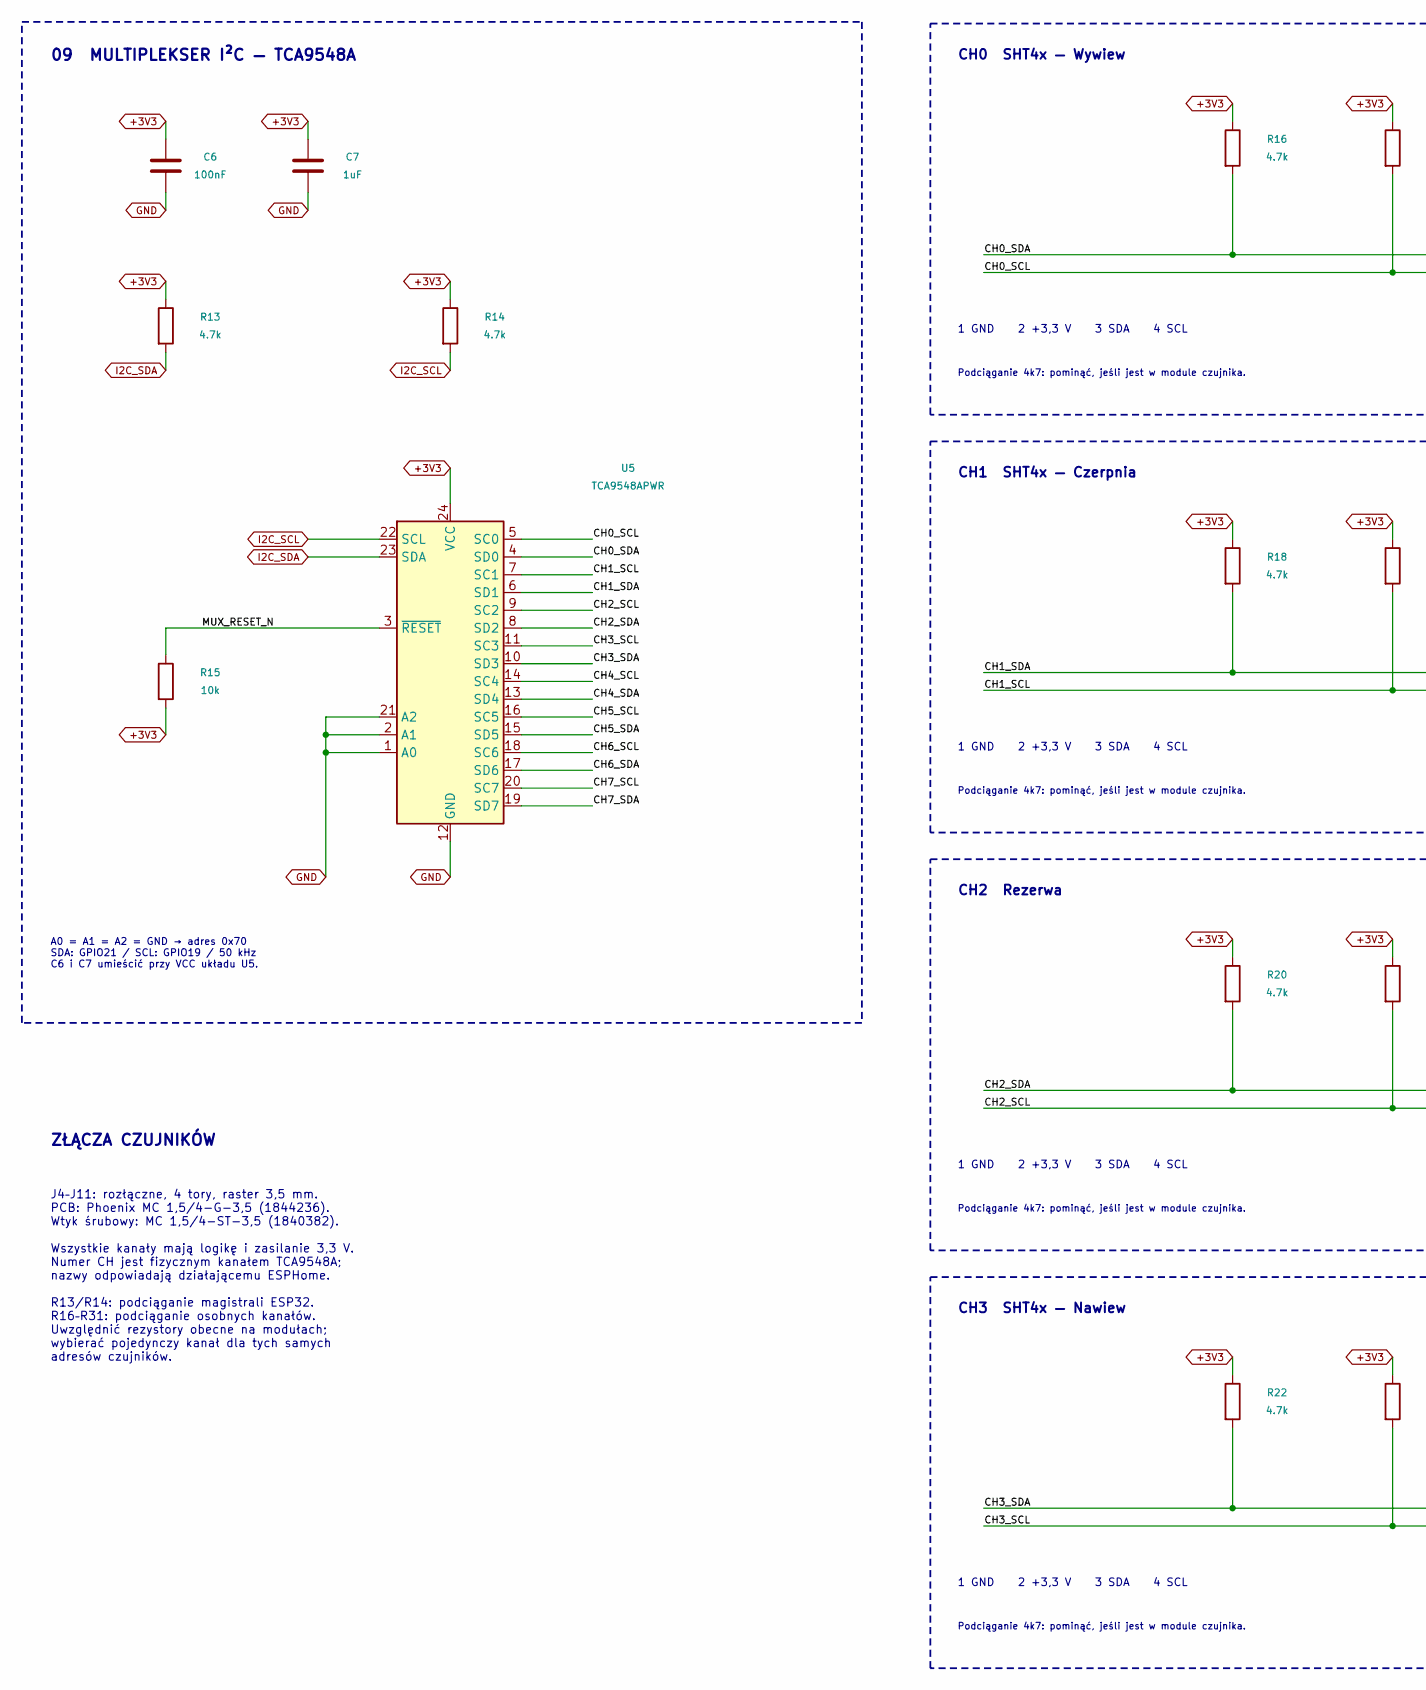
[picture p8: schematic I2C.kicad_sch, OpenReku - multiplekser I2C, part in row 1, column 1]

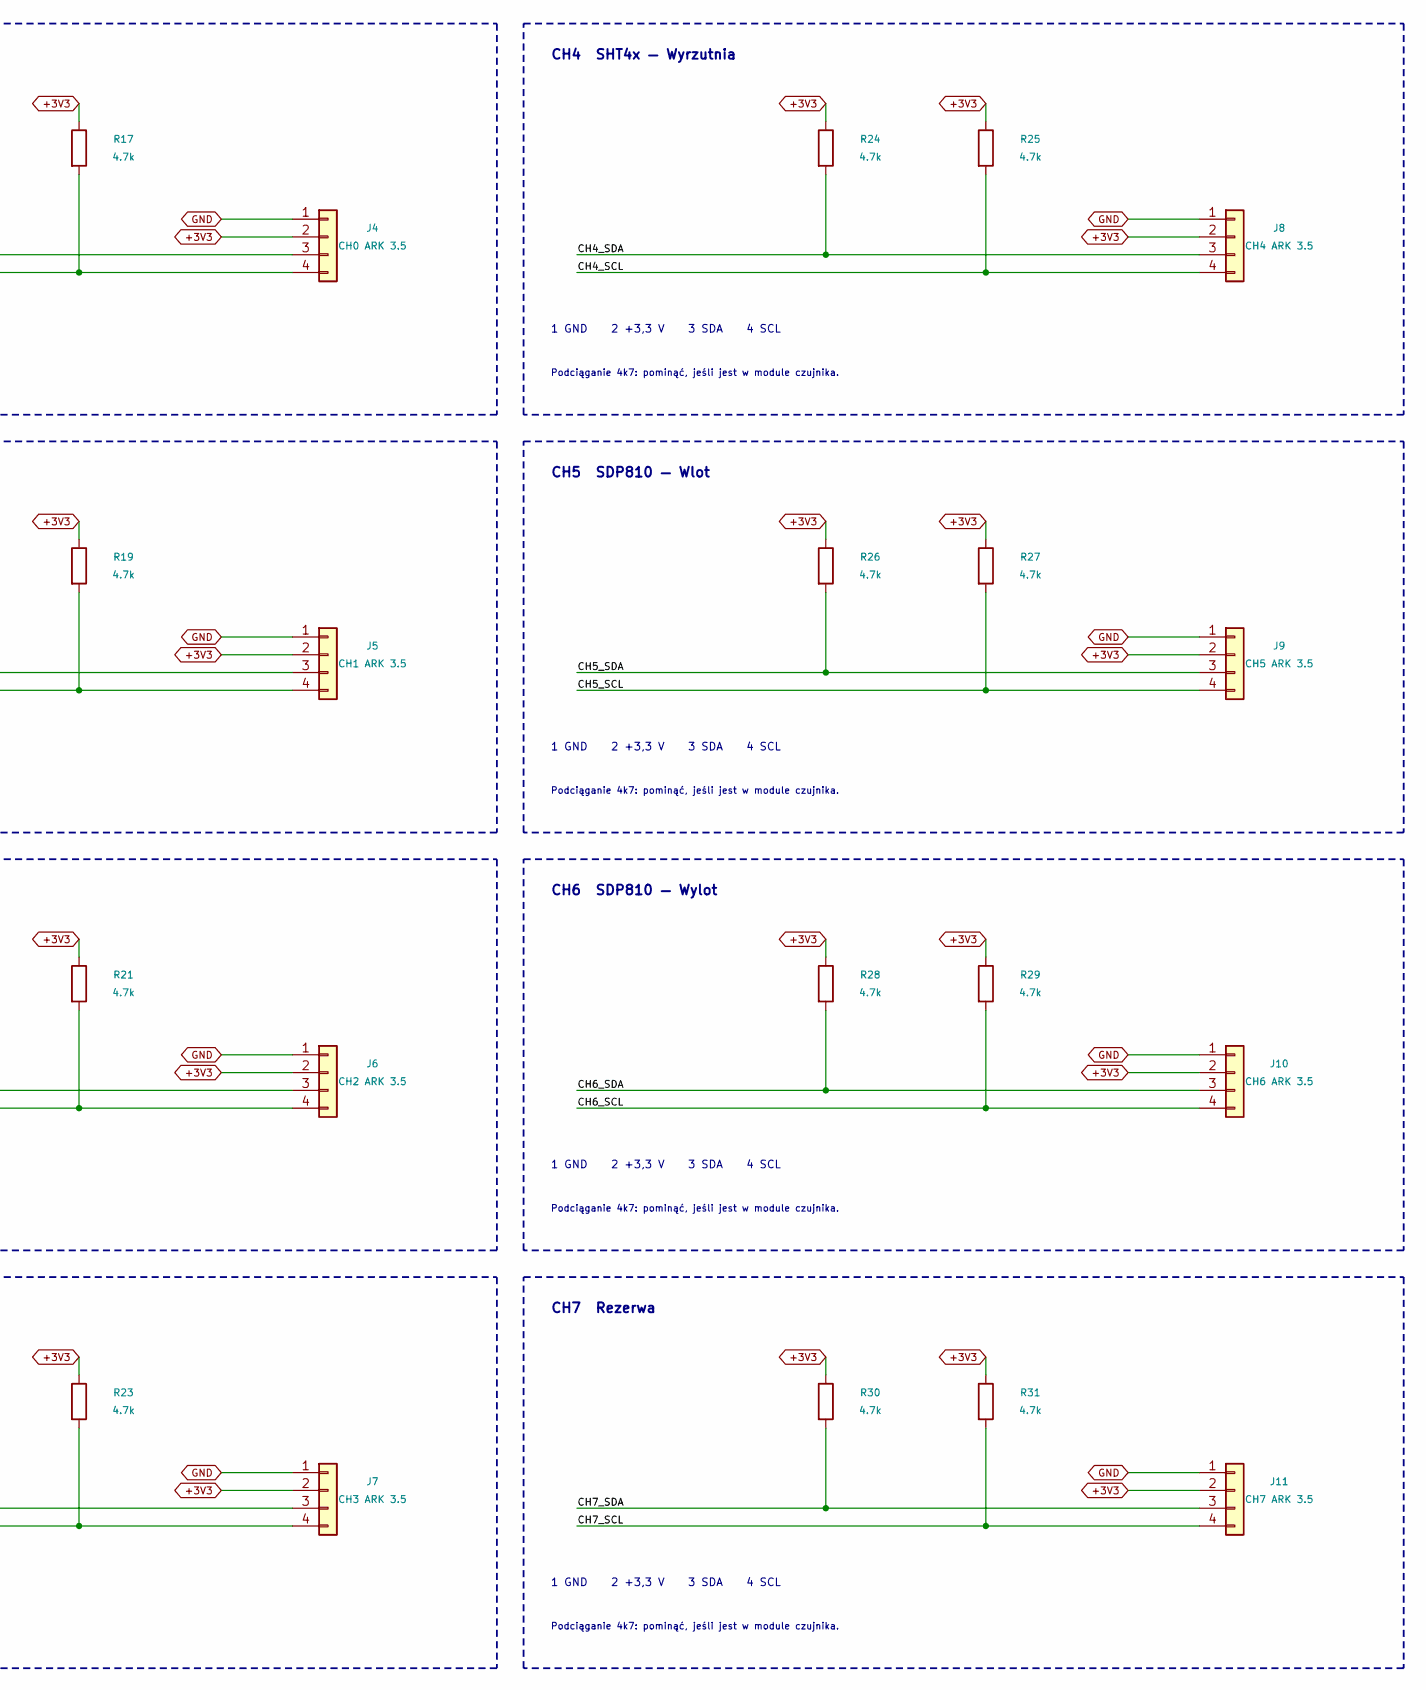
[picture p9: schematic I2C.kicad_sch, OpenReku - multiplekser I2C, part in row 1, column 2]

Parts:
C6: 100nF; C_1206_3216Metric
C7: 1uF; C_1206_3216Metric
J4: CH0 ARK 3.5; PhoenixContact_MC_1,5_4-G-3.5_1x04_P3.50mm_Horizontal_Edge; MPN 1844236
J5: CH1 ARK 3.5; PhoenixContact_MC_1,5_4-G-3.5_1x04_P3.50mm_Horizontal_Edge; MPN 1844236
J6: CH2 ARK 3.5; PhoenixContact_MC_1,5_4-G-3.5_1x04_P3.50mm_Horizontal_Edge; MPN 1844236
J7: CH3 ARK 3.5; PhoenixContact_MC_1,5_4-G-3.5_1x04_P3.50mm_Horizontal_Edge; MPN 1844236
J8: CH4 ARK 3.5; PhoenixContact_MC_1,5_4-G-3.5_1x04_P3.50mm_Horizontal_Edge; MPN 1844236
J9: CH5 ARK 3.5; PhoenixContact_MC_1,5_4-G-3.5_1x04_P3.50mm_Horizontal_Edge; MPN 1844236
J10: CH6 ARK 3.5; PhoenixContact_MC_1,5_4-G-3.5_1x04_P3.50mm_Horizontal_Edge; MPN 1844236
J11: CH7 ARK 3.5; PhoenixContact_MC_1,5_4-G-3.5_1x04_P3.50mm_Horizontal_Edge; MPN 1844236
R13, R14, R16, R17, R18, R19, R20, R21, R22, R23, R24, R25, R26, R27, R28, R29, R30, R31: 4.7k; R_1206_3216Metric
R15: 10k; R_1206_3216Metric
U5: TCA9548APWR; TSSOP-24_4.4x7.8mm_P0.65mm; MPN TCA9548APWR

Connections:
+3V3: C6.1, C7.1, J4.2, J5.2, J6.2, J7.2, J8.2, J9.2, J10.2, J11.2, R13.1, R14.1, R15.2, R16.1, R17.1, R18.1, R19.1, R20.1, R21.1, R22.1, R23.1, R24.1, R25.1, R26.1, R27.1, R28.1, R29.1, R30.1, R31.1, U5.24 (VCC); also elsewhere on the board
/I2C — multiplekser i czujniki/CH0_SCL: J4.4, R17.2, U5.5 (SC0)
/I2C — multiplekser i czujniki/CH0_SDA: J4.3, R16.2, U5.4 (SD0)
/I2C — multiplekser i czujniki/CH1_SCL: J5.4, R19.2, U5.7 (SC1)
/I2C — multiplekser i czujniki/CH1_SDA: J5.3, R18.2, U5.6 (SD1)
/I2C — multiplekser i czujniki/CH2_SCL: J6.4, R21.2, U5.9 (SC2)
/I2C — multiplekser i czujniki/CH2_SDA: J6.3, R20.2, U5.8 (SD2)
/I2C — multiplekser i czujniki/CH3_SCL: J7.4, R23.2, U5.11 (SC3)
/I2C — multiplekser i czujniki/CH3_SDA: J7.3, R22.2, U5.10 (SD3)
/I2C — multiplekser i czujniki/CH4_SCL: J8.4, R25.2, U5.14 (SC4)
/I2C — multiplekser i czujniki/CH4_SDA: J8.3, R24.2, U5.13 (SD4)
/I2C — multiplekser i czujniki/CH5_SCL: J9.4, R27.2, U5.16 (SC5)
/I2C — multiplekser i czujniki/CH5_SDA: J9.3, R26.2, U5.15 (SD5)
/I2C — multiplekser i czujniki/CH6_SCL: J10.4, R29.2, U5.18 (SC6)
/I2C — multiplekser i czujniki/CH6_SDA: J10.3, R28.2, U5.17 (SD6)
/I2C — multiplekser i czujniki/CH7_SCL: J11.4, R31.2, U5.20 (SC7)
/I2C — multiplekser i czujniki/CH7_SDA: J11.3, R30.2, U5.19 (SD7)
/I2C — multiplekser i czujniki/MUX_RESET_N: R15.1, U5.3 (~RESET)
GND: C6.2, C7.2, J4.1, J5.1, J6.1, J7.1, J8.1, J9.1, J10.1, J11.1, U5.1 (A0), U5.2 (A1), U5.12 (GND), U5.21 (A2); also elsewhere on the board
I2C_SCL: R14.2, U5.22 (SCL); also elsewhere on the board
I2C_SDA: R13.2, U5.23 (SDA); also elsewhere on the board

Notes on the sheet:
09 MULTIPLEKSER I²C — TCA9548A
A0 = A1 = A2 = GND → adres 0x70 SDA: GPIO21 / SCL: GPIO19 / 50 kHz C6 i C7 umieścić przy VCC układu U5.
CH0 SHT4x — Wywiew
1 GND 2 +3,3 V 3 SDA 4 SCL
Podciąganie 4k7: pominąć, jeśli jest w module czujnika.
CH1 SHT4x — Czerpnia
CH2 Rezerwa
CH3 SHT4x — Nawiew
CH4 SHT4x — Wyrzutnia
CH5 SDP810 — Wlot
CH6 SDP810 — Wylot
CH7 Rezerwa
ZŁĄCZA CZUJNIKÓW
J4–J11: rozłączne, 4 tory, raster 3,5 mm. PCB: Phoenix MC 1,5/4-G-3,5 (1844236). Wtyk śrubowy: MC 1,5/4-ST-3,5 (1840382). Wszystkie kanały mają logikę i zasilanie 3,3 V. Numer CH jest fizycznym kanałem TCA9548A; nazwy odpowiadają działającemu ESPHome. R13/R14: podciąganie magistrali ESP32. R16–R31: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

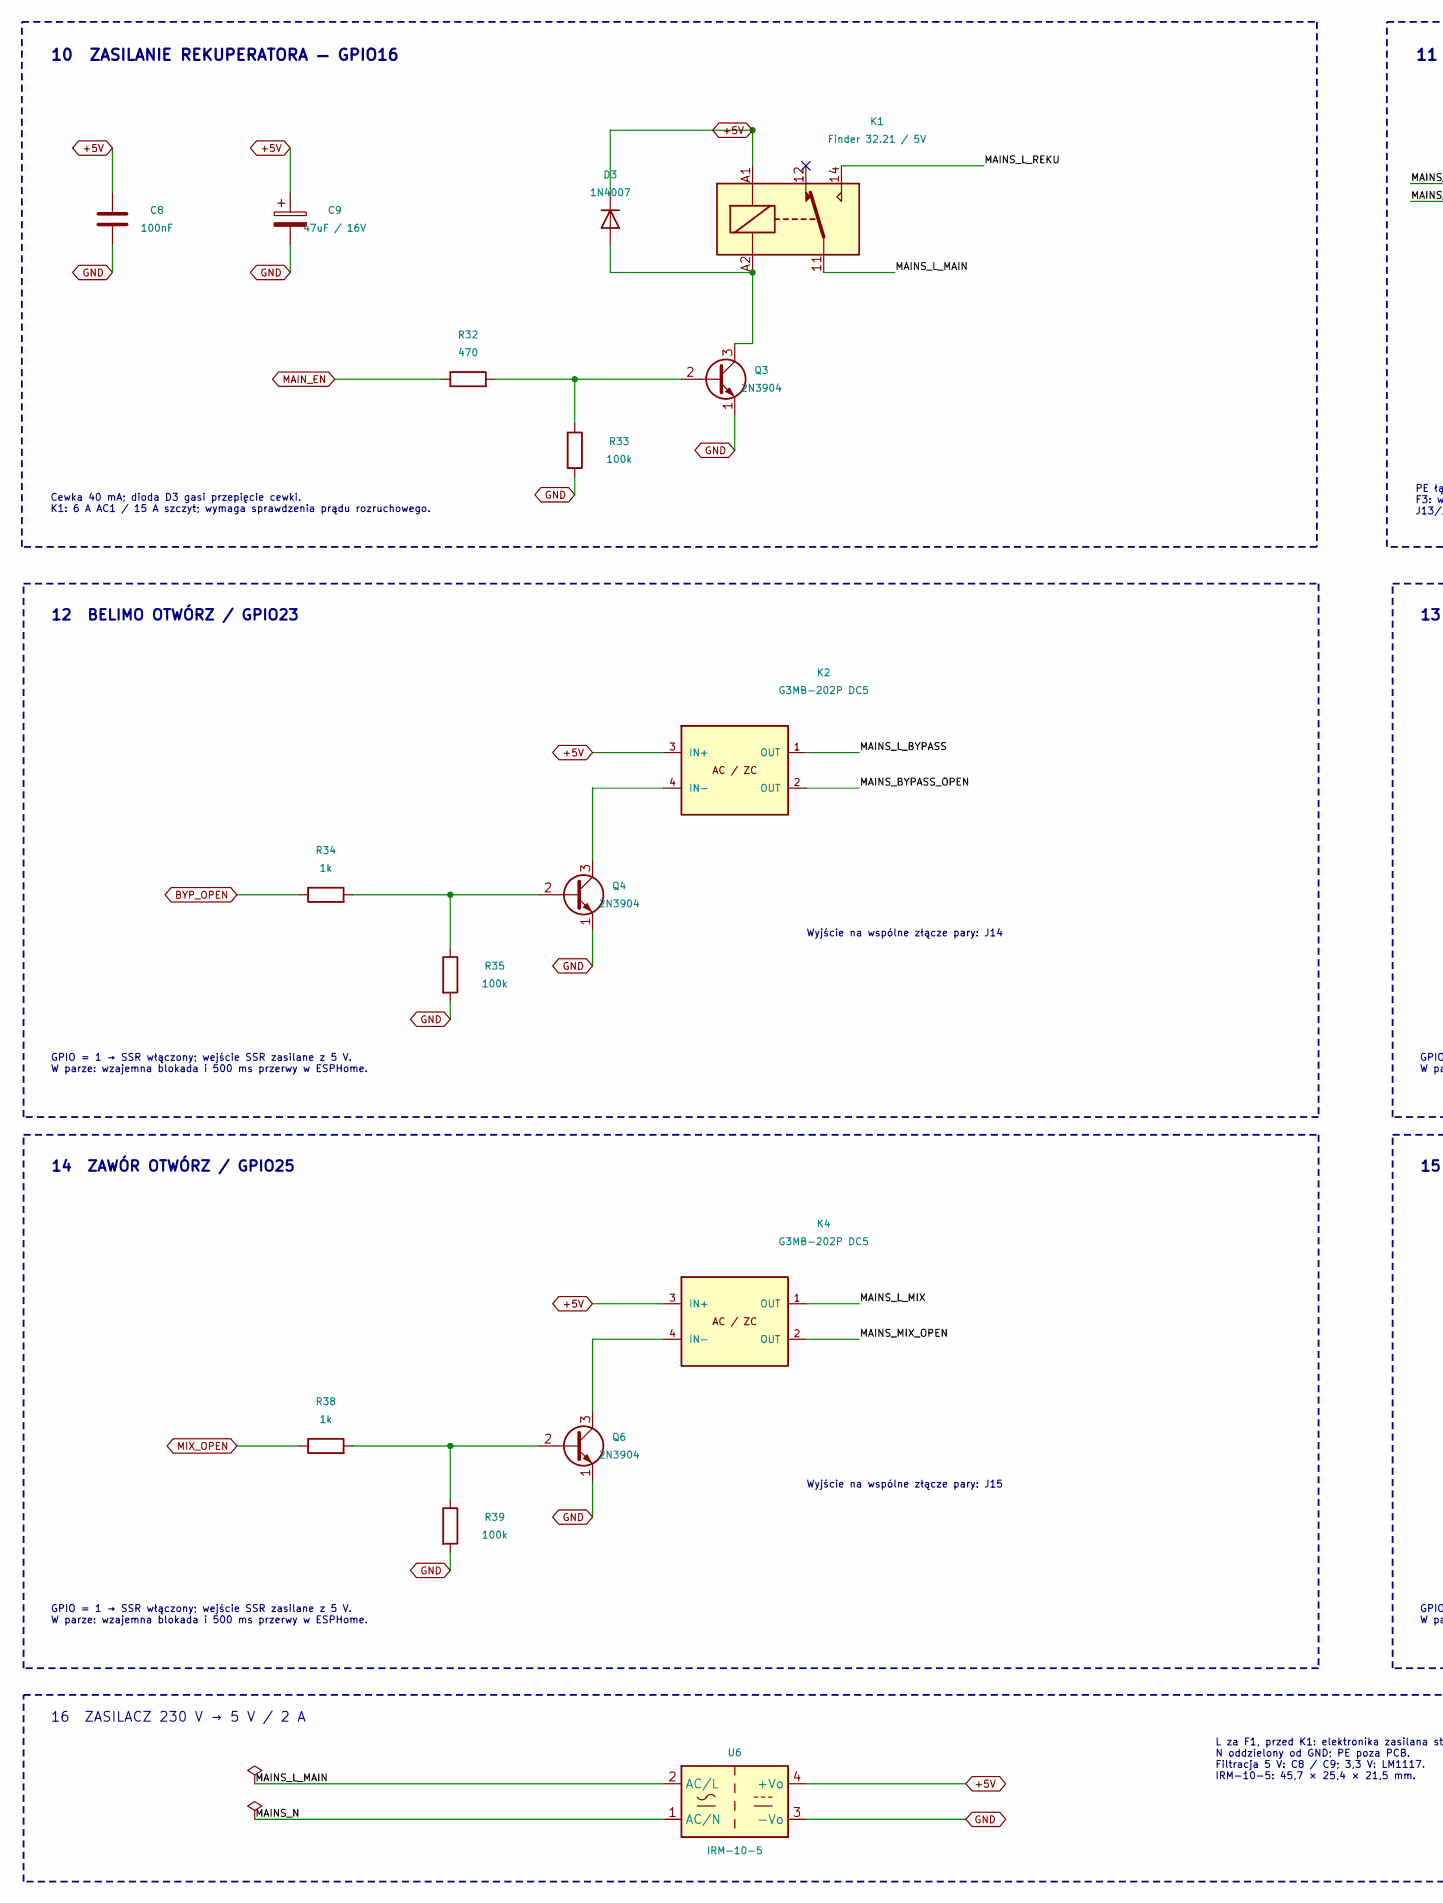
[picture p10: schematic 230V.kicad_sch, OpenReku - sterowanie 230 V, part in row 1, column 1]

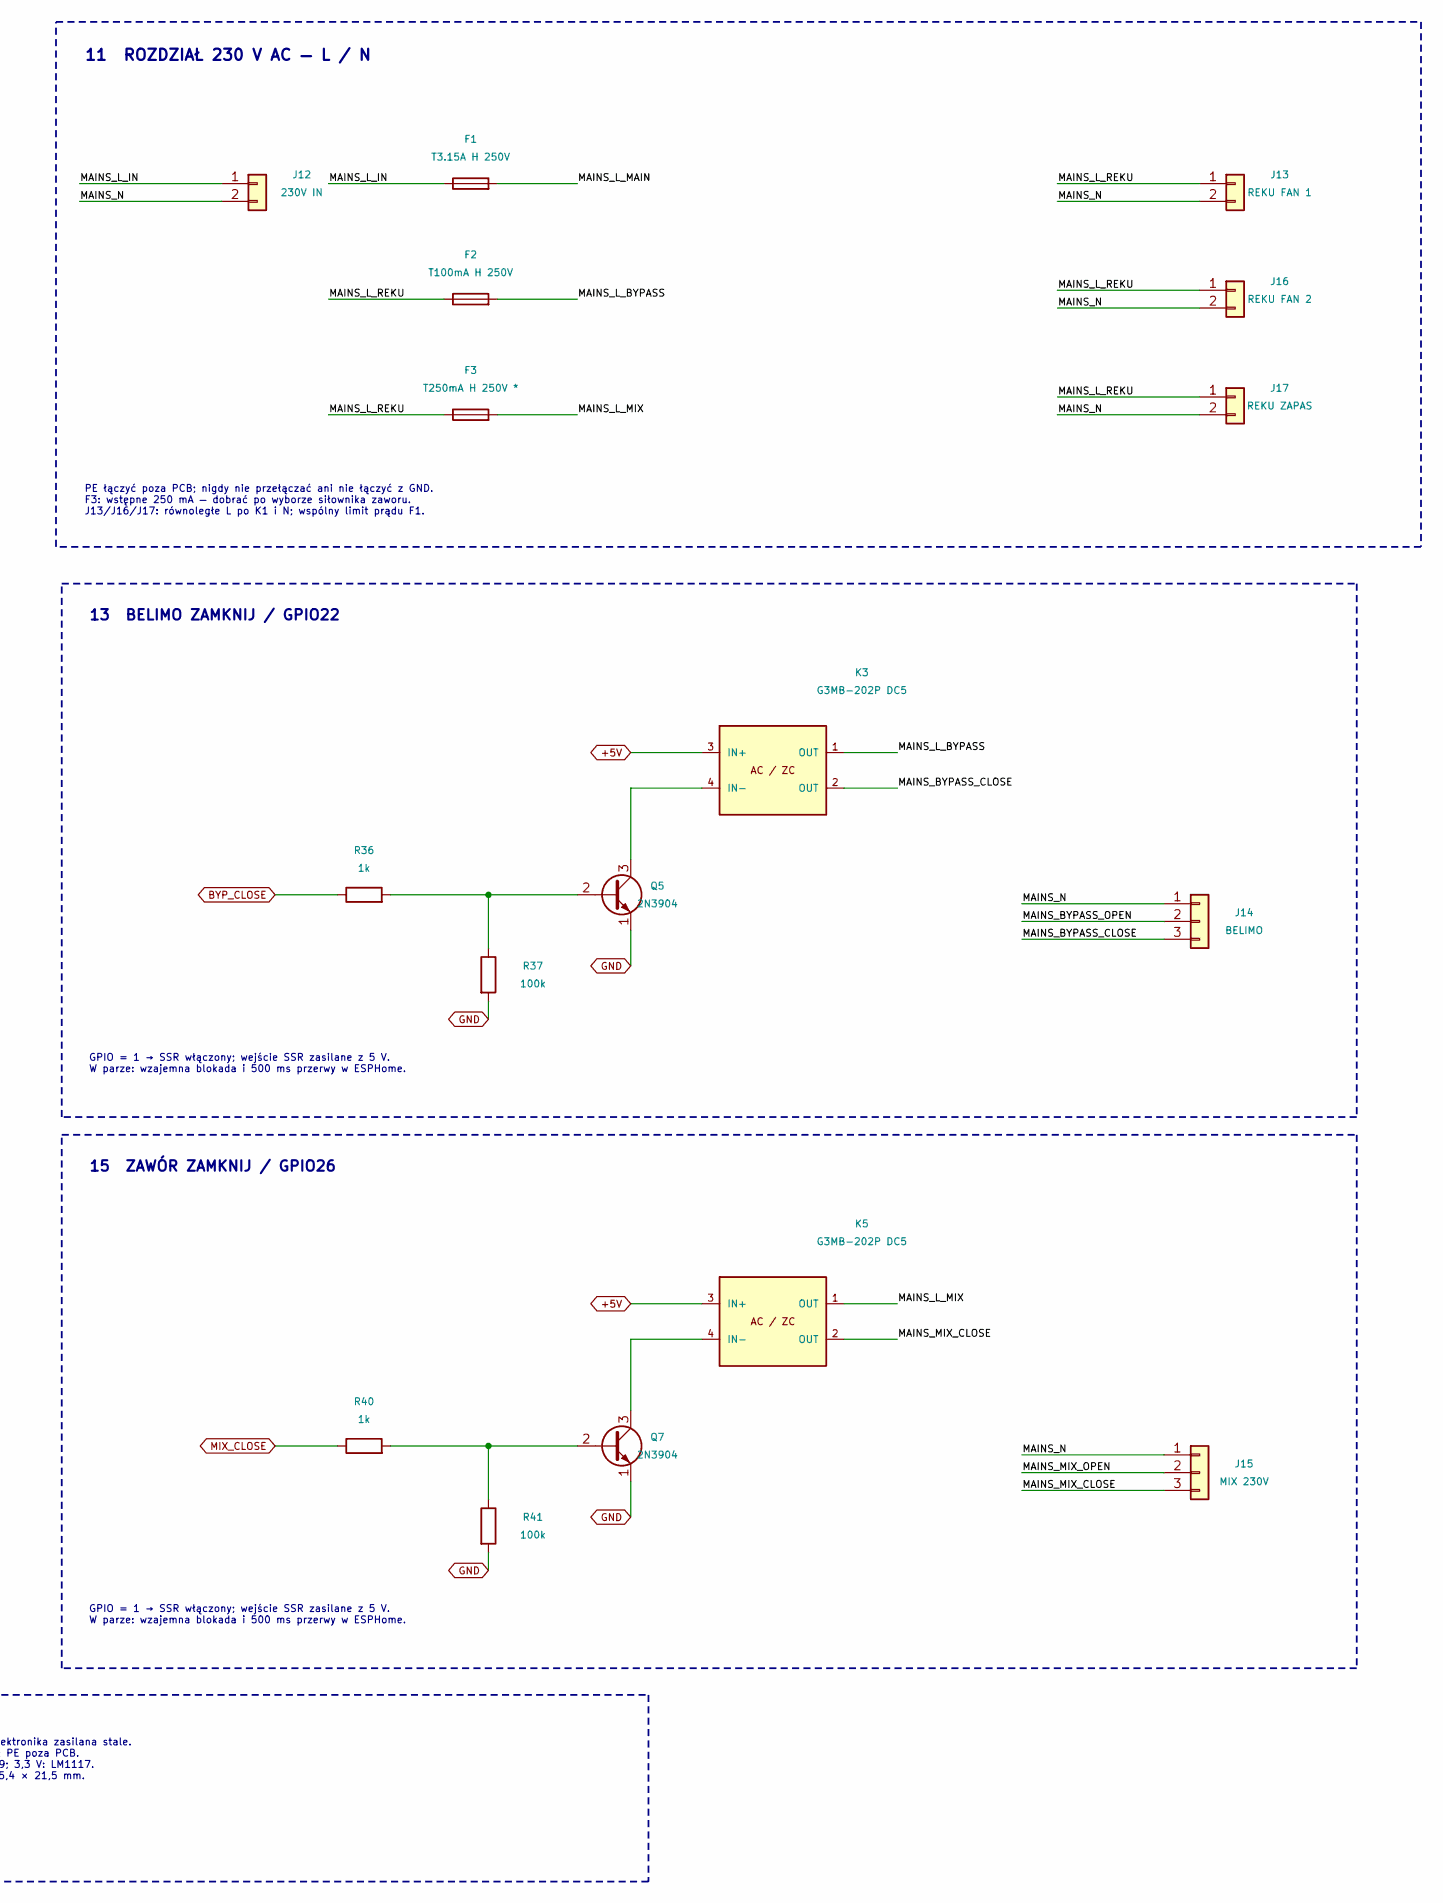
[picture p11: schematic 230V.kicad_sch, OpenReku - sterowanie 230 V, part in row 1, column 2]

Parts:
C8: 100nF; C_1206_3216Metric
C9: 47uF / 16V; CP_Radial_D5.0mm_P2.00mm
D3: 1N4007; D_DO-41_SOD81_P10.16mm_Horizontal
F1: T3.15A H 250V; Fuseholder_Cylinder-5x20mm_Schurter_0031_8201_Horizontal_Op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
F2: T100mA H 250V; Fuseholder_Cylinder-5x20mm_Schurter_0031_8201_Horizontal_Op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
F3: T250mA H 250V *; Fuseholder_Cylinder-5x20mm_Schurter_0031_8201_Horizontal_Op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
J12: 230V IN; PhoenixContact_MSTBA_2,5_2-G-5,08_1x02_P5.08mm_Horizontal_E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; MPN 1757242
J13: REKU FAN 1; PhoenixContact_MSTBA_2,5_2-G-5,08_1x02_P5.08mm_Horizontal_E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; MPN 1757242
J14: BELIMO; PhoenixContact_MSTBA_2,5_3-G-5,08_1x03_P5.08mm_Horizontal_E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; MPN 1757255
J15: MIX 230V; PhoenixContact_MSTBA_2,5_3-G-5,08_1x03_P5.08mm_Horizontal_E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; MPN 1757255
J16: REKU FAN 2; PhoenixContact_MSTBA_2,5_2-G-5,08_1x02_P5.08mm_Horizontal_E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; MPN 1757242
J17: REKU ZAPAS; PhoenixContact_MSTBA_2,5_2-G-5,08_1x02_P5.08mm_Horizontal_E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; MPN 1757242
K1: Finder 32.21 / 5V; Relay_SPDT_Finder_32.21-x000; MPN 32.21.7.005.4000
K2, K3, K4, K5: G3MB-202P DC5; Omron_G3MB-202P_SIP4; MPN G3MB-202P DC5
Q3, Q4, Q5, Q6, Q7: 2N3904; TO-92_Inline
R32: 470; R_1206_3216Metric
R33, R35, R37, R39, R41: 100k; R_1206_3216Metric
R34, R36, R38, R40: 1k; R_1206_3216Metric
U6: IRM-10-5; Converter_ACDC_MeanWell_IRM-10-xx_THT

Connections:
+5V: C8.1, C9.1, D3.1 (K), K1.A1, K2.3 (IN+), K3.3 (IN+), K4.3 (IN+), K5.3 (IN+), U6.4 (+Vo); also elsewhere on the board
/230V/MAINS_BYPASS_CLOSE: J14.3, K3.2 (OUT)
/230V/MAINS_BYPASS_OPEN: J14.2, K2.2 (OUT)
/230V/MAINS_L_BYPASS: F2.2, K2.1 (OUT), K3.1 (OUT)
/230V/MAINS_L_IN: F1.1, J12.1
/230V/MAINS_L_MAIN: F1.2, K1.11, U6.2 (AC/L)
/230V/MAINS_L_MIX: F3.2, K4.1 (OUT), K5.1 (OUT)
/230V/MAINS_L_REKU: F2.1, F3.1, J13.1, J16.1, J17.1, K1.14
/230V/MAINS_MIX_CLOSE: J15.3, K5.2 (OUT)
/230V/MAINS_MIX_OPEN: J15.2, K4.2 (OUT)
/230V/MAINS_N: J12.2, J13.2, J14.1, J15.1, J16.2, J17.2, U6.1 (AC/N)
BYP_CLOSE: R36.1; also elsewhere on the board
BYP_OPEN: R34.1; also elsewhere on the board
GND: C8.2, C9.2, Q3.1 (E), Q4.1 (E), Q5.1 (E), Q6.1 (E), Q7.1 (E), R33.2, R35.2, R37.2, R39.2, R41.2, U6.3 (-Vo); also elsewhere on the board
MAIN_EN: R32.1; also elsewhere on the board
MIX_CLOSE: R40.1; also elsewhere on the board
MIX_OPEN: R38.1; also elsewhere on the board
unnamed: D3.2 (A), K1.A2, Q3.3 (C)
unnamed: K2.4 (IN-), Q4.3 (C)
unnamed: K3.4 (IN-), Q5.3 (C)
unnamed: K4.4 (IN-), Q6.3 (C)
unnamed: K5.4 (IN-), Q7.3 (C)
unnamed: Q3.2 (B), R32.2, R33.1
unnamed: Q4.2 (B), R34.2, R35.1
unnamed: Q5.2 (B), R36.2, R37.1
unnamed: Q6.2 (B), R38.2, R39.1
unnamed: Q7.2 (B), R40.2, R41.1

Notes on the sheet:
10 ZASILANIE REKUPERATORA — GPIO16
Cewka 40 mA; dioda D3 gasi przepięcie cewki. K1: 6 A AC1 / 15 A szczyt; wymaga sprawdzenia prądu rozruchowego.
11 ROZDZIAŁ 230 V AC — L / N
PE łączyć poza PCB; nigdy nie przełączać ani nie łączyć z GND. F3: wstępne 250 mA — dobrać po wyborze siłownika zaworu. J13/J16/J17: równoległe L po K1 i N; wspólny limit prądu F1.
12 BELIMO OTWÓRZ / GPIO23
Wyjście na wspólne złącze pary: J14
GPIO = 1 → SSR włączony; wejście SSR zasilane z 5 V. W parze: wzajemna blokada i 500 ms przerwy w ESPHome.
13 BELIMO ZAMKNIJ / GPIO22
14 ZAWÓR OTWÓRZ / GPIO25
Wyjście na wspólne złącze pary: J15
15 ZAWÓR ZAMKNIJ / GPIO26
16 ZASILACZ 230 V → 5 V / 2 A
L za F1, przed K1: elektronika zasilana stale. N oddzielony od GND; PE poza PCB. Filtracja 5 V: C8 / C9; 3,3 V: LM1117. IRM-10-5: 45,7 × 25,4 × 21,5 mm.

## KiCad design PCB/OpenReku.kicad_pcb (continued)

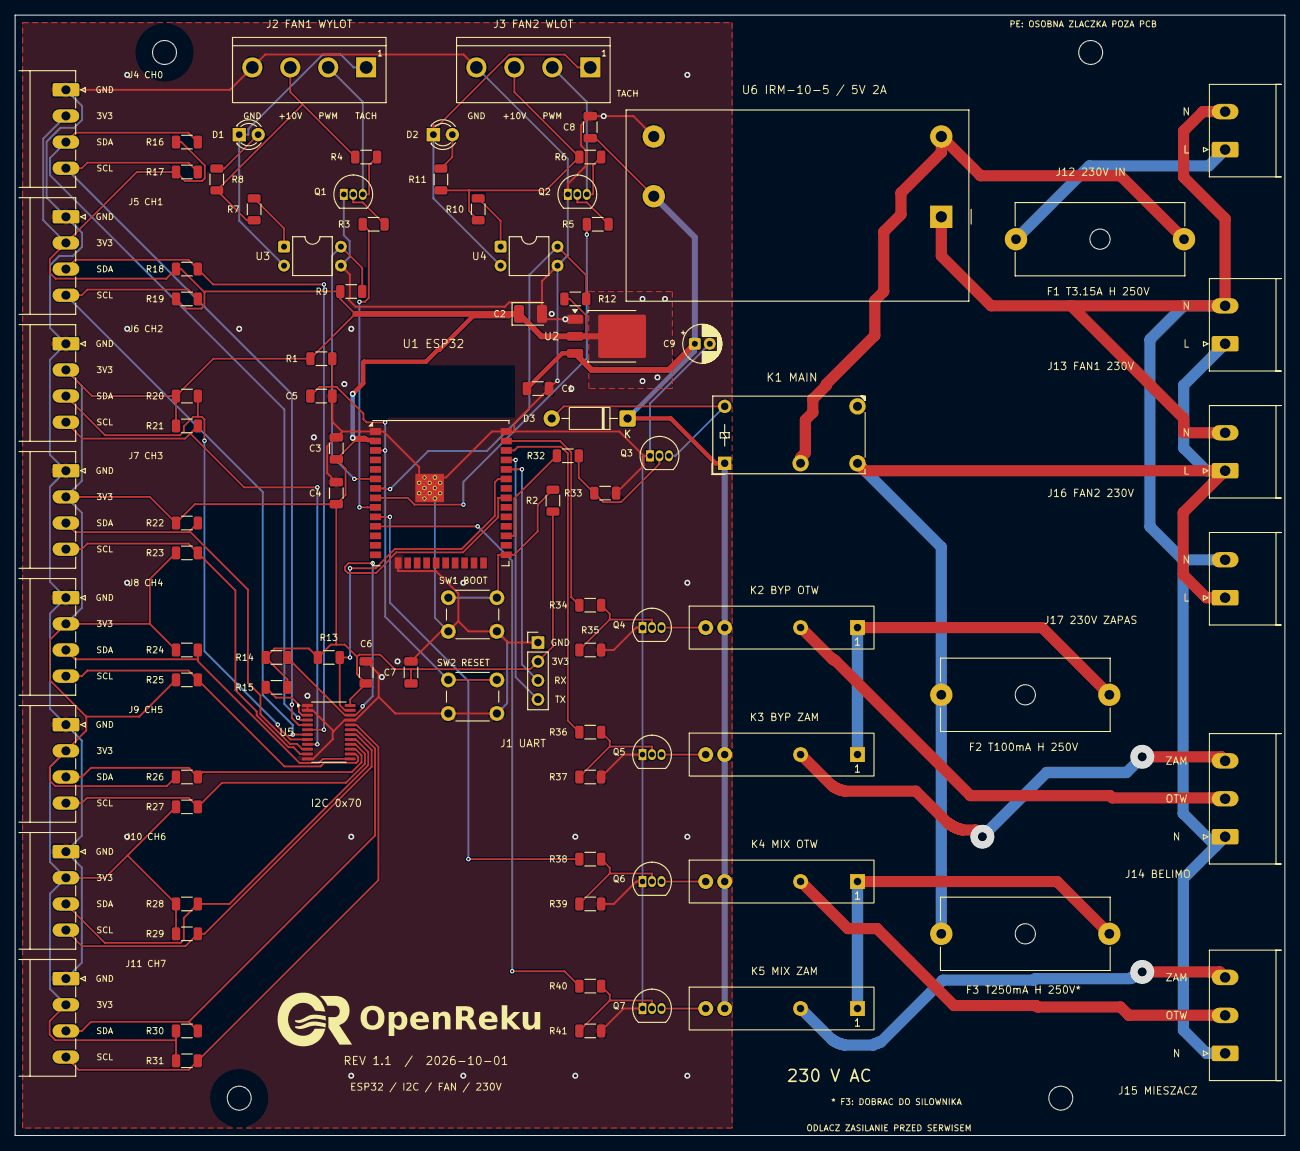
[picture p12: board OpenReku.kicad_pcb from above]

Board: 2 copper layers, 170.0 x 150.0 mm, 98 parts (0 on the bottom side), 67 nets.

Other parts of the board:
H1, H2, H3, H4: MountingHole_3.2mm_M3
LOGO1: OpenReku logo; Logo_OpenReku_36mm

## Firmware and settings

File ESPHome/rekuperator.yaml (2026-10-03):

# SPDX-License-Identifier: PolyForm-Noncommercial-1.0.0
# Required Notice: Copyright 2026 Sauron — OpenReku (https://github.com/Saur0o0n/OpenReku)
# License: https://polyformproject.org/licenses/noncommercial/1.0.0

substitutions:
  devicename: rekuperator
  friendly_name: Rekuperator
  belimo_pulse_time: 88s

  # Venturi geometry
  venturi_D_mm: "194.0"   # upstream pipe diameter (200-2*3)
  venturi_d_mm: "154.0"   # throat diameter (160-2*3)

  # Assumed absolute air pressure for density calculation
  air_pressure_pa: "101325.0"

  # Venturi zero-noise threshold [hPa] - na postoju maksymalny zmierzony blad byl 0,00042
  venturi_noise: "0.0005f"

esphome:
  name: ${devicename}
  friendly_name: ${friendly_name}
  on_boot:
    priority: -100
    then:
      # Restore the last completed test before accepting HA connections.
      - lambda: |-
          id(filter_test_wlot_flow_per_pwm).publish_state(id(filter_test_saved_results)[0]);
          id(filter_test_wylot_flow_per_pwm).publish_state(id(filter_test_saved_results)[1]);
          id(filter_test_wlot_rpm_per_pwm).publish_state(id(filter_test_saved_results)[2]);
          id(filter_test_wylot_rpm_per_pwm).publish_state(id(filter_test_saved_results)[3]);
      - delay: 500ms
      - fan.turn_off: internal_fan1_pwm
      - fan.turn_off: internal_fan2_pwm
  on_shutdown:
    then:
      - fan.turn_off: internal_fan1_pwm
      - fan.turn_off: internal_fan2_pwm
      - switch.turn_off: internal_recuperator_main_relay

esp32:
  variant: esp32
  framework:
    type: esp-idf

logger:

api:
  encryption:
    key: !secret rekuperator_api_encryption_key

  # HA owns the schedule; this action only starts the local procedure.
  actions:
    - action: run_filter_test
      then:
        - script.execute: filter_test_cycle

ota:
  - platform: esphome

wifi:
  ssid: !secret wifi_ssid
  password: !secret wifi_password
  ap:
    ssid: Rekuperator Fallback Hotspot
    password: !secret rekuperator_fallback_ap_password

captive_portal:

web_server:
  port: 80

i2c:
  id: i2c_main
  sda: GPIO21
  scl: GPIO19
  frequency: 50kHz
  scan: true

tca9548a:
  - id: mux0
    address: 0x70
    i2c_id: i2c_main
    channels:
      # CH0 -> SHT40 "Czerpnia"
      - bus_id: i2c_ch0
        channel: 0

      # CH1 -> SHT40 "Wyrzutnia"
      - bus_id: i2c_ch1
        channel: 1

      # Kanał 2 ma uszkodzony styk

      # CH3 -> SHT40 "Nawiew"
      - bus_id: i2c_ch2
        channel: 3

      # CH4 -> SHT40 "Wywiew"
      - bus_id: i2c_ch3
        channel: 4

      # CH5 -> SDP810-125Pa Venturi "Wlot"
      - bus_id: i2c_ch4
        channel: 5

      # CH6 -> SDP810-125Pa Venturi "Wylot"
      - bus_id: i2c_ch5
        channel: 6

globals:
  # Bypass deadband in degrees C and uninterrupted condition time in seconds.
  - id: bypass_temperature_threshold
    type: float
    restore_value: false
    initial_value: '0.5f'

  - id: bypass_hold_seconds
    type: uint32_t
    restore_value: false
    initial_value: '300'

  # Pending transition: -1 = none, 0 = close, 1 = open.
  - id: bypass_pending_target
    type: int
    restore_value: false
    initial_value: '-1'

  - id: bypass_pending_since
    type: uint32_t
    restore_value: false
    initial_value: '0'

  # Last completed test: Wlot Q/PWM, Wylot Q/PWM, Wlot RPM/PWM, Wylot RPM/PWM.
  # One persistent snapshot; unknown until the first completed test.
  - id: filter_test_saved_results
    type: float[4]
    restore_value: true
    initial_value: '{NAN, NAN, NAN, NAN}'

  # Fan speed percentage (1-100), before the existing LEDC min_power scaling.
  - id: filter_test_pwm
    type: int
    restore_value: false
    initial_value: '30'

  # Set only by local service procedures; never restored after an ESP restart.
  - id: internal_service_mode
    type: bool
    restore_value: false
    initial_value: 'false'

  # Temporary test snapshot and accumulators; lost on ESP restart.
  - id: filter_test_prev_sync_mode
    type: std::string
    restore_value: false
    initial_value: '"Brak"'

  - id: filter_test_prev_fan1_on
    type: bool
    restore_value: false
    initial_value: 'false'

  - id: filter_test_prev_fan2_on
    type: bool
    restore_value: false
    initial_value: 'false'

  - id: filter_test_prev_fan1_speed
    type: int
    restore_value: false
    initial_value: '0'

  - id: filter_test_prev_fan2_speed
    type: int
    restore_value: false
    initial_value: '0'

  - id: filter_test_prev_bypass_open
    type: bool
    restore_value: false
    initial_value: 'false'

  - id: filter_test_running_pwm
    type: int
    restore_value: false
    initial_value: '30'

  - id: filter_test_wlot_flow_sum
    type: float
    restore_value: false
    initial_value: '0.0f'

  - id: filter_test_wylot_flow_sum
    type: float
    restore_value: false
    initial_value: '0.0f'

  - id: filter_test_wlot_rpm_sum
    type: float
    restore_value: false
    initial_value: '0.0f'
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

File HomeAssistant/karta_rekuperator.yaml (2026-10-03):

# SPDX-License-Identifier: PolyForm-Noncommercial-1.0.0
# Required Notice: Copyright 2026 Sauron — OpenReku (https://github.com/Saur0o0n/OpenReku)
# License: https://polyformproject.org/licenses/noncommercial/1.0.0

type: picture-elements
image: /local/rekuperator2.jpg
elements:
  - type: state-label
    entity: sensor.kotlownia_rekuperator_wywiew_temperatura
    style:
      top: 38.55%
      left: 15.35%
      transform: translate(-50%, -50%)
      color: '#111111'
      font-size: 20px
      font-weight: 700
      line-height: 1
  - type: state-label
    entity: sensor.kotlownia_rekuperator_wywiew_wilgotnosc
    style:
      top: 43.50%
      left: 14.75%
      transform: translate(-50%, -50%)
      color: '#111111'
      font-size: 20px
      font-weight: 700
      line-height: 1
  - type: state-label
    entity: sensor.kotlownia_rekuperator_wylot_rpm
    style:
      top: 11.55%
      left: 55.00%
      transform: translate(-50%, -50%)
      color: '#111111'
      font-size: 17px
      font-weight: 700
      line-height: 1
  - type: state-label
    entity: fan.kotlownia_rekuperator_wylot_pwm
    attribute: percentage
    suffix: '%'
    style:
      top: 15.05%
      left: 55.00%
      transform: translate(-50%, -50%)
      color: '#111111'
      font-size: 17px
      font-weight: 700
      line-height: 1
  - type: state-label
    entity: sensor.kotlownia_rekuperator_wylot_przeplyw_powietrza
    style:
      top: 18.75%
      left: 55.00%
      transform: translate(-50%, -50%)
      color: '#111111'
      font-size: 17px
      font-weight: 700
      line-height: 1
  - type: state-label
    entity: sensor.kotlownia_rekuperator_nawiew_temperatura
    style:
      top: 37.20%
      left: 89.00%
      transform: translate(-50%, -50%)
      color: '#111111'
      font-size: 20px
      font-weight: 700
      line-height: 1
  - type: state-label
    entity: sensor.kotlownia_rekuperator_nawiew_wilgotnosc
    style:
      top: 41.75%
      left: 89.00%
      transform: translate(-50%, -50%)
      color: '#111111'
      font-size: 20px
      font-weight: 700
      line-height: 1
  - type: state-label
    entity: sensor.kotlownia_rekuperator_czerpnia_temperatura
    style:
      top: 64.50%
      left: 15.35%
      transform: translate(-50%, -50%)
      color: '#111111'
      font-size: 20px
      font-weight: 700
      line-height: 1
  - type: state-label
    entity: sensor.kotlownia_rekuperator_czerpnia_wilgotnosc
    style:
      top: 69.30%
      left: 14.75%
      transform: translate(-50%, -50%)
      color: '#111111'
      font-size: 20px
      font-weight: 700
      line-height: 1
  - type: state-label
    entity: sensor.kotlownia_rekuperator_wlot_rpm
    style:
      top: 88.00%
      left: 54.10%
      transform: translate(-50%, -50%)
      color: '#111111'
      font-size: 17px
      font-weight: 700
      line-height: 1
  - type: state-label
    entity: fan.kotlownia_rekuperator_wlot_pwm
    attribute: percentage
    suffix: '%'
    style:
      top: 91.30%
      left: 54.10%
      transform: translate(-50%, -50%)
      color: '#111111'
      font-size: 17px
      font-weight: 700
      line-height: 1
  - type: state-label
    entity: sensor.kotlownia_rekuperator_wlot_przeplyw_powietrza
    style:
      top: 94.70%
      left: 54.60%
      transform: translate(-50%, -50%)
      color: '#111111'
      font-size: 17px
      font-weight: 700
      line-height: 1
  - type: state-label
    entity: sensor.kotlownia_rekuperator_wyrzutnia_temperatura
    style:
      top: 65.05%
      left: 89.00%
      transform: translate(-50%, -50%)
      color: '#111111'
      font-size: 20px
      font-weight: 700
      line-height: 1
  - type: state-label
    entity: sensor.kotlownia_rekuperator_wyrzutnia_wilgotnosc
    style:
      top: 69.80%
      left: 89.00%
      transform: translate(-50%, -50%)
      color: '#111111'
      font-size: 20px
      font-weight: 700
      line-height: 1
  - type: state-label
    entity: valve.kotlownia_rekuperator_by_pass
    tap_action:
      action: more-info
    style:
      top: 33.20%
      left: 46.50%
      transform: translate(-50%, -50%)
      color: '#111111'
      font-size: 18px
      font-weight: 700
      line-height: 1
  - type: state-label
    entity: sensor.kotlownia_shellypmminig3_rekuperator_power
    prefix: 'Pobór: '
    style:
      top: 4.60%
      left: 87.80%
      transform: translate(-50%, -50%)
      color: '#263238'
      font-size: 16px
      font-weight: 700
      line-height: 1
  - type: state-icon
    entity: switch.kotlownia_rekuperator_zasilanie_rekuperatora
    icon: mdi:power
    state_color: true
    tap_action:
      action: more-info
    style:
      top: 4.60%
      left: 94.80%
      --mdc-icon-size: 33px
      --state-switch-on-color: '#43A047'
      --state-switch-off-color: '#F57C00'
      # Przycisk zasilania pozostaje nad nakładką blokującą kartę.
      z-index: 20
  - type: custom:hui-element
    card_type: custom:gauge-card-pro
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

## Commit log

2026-10-01 Add BOM for PCB revision 1.0
    [BOM.csv]
2026-10-01 Add PCB v1.0 KiCad sources, production Gerbers and ignore rules
    [230V.kicad_sch, I2C.kicad_sch, Rekuperator.kicad_pcb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]
2026-10-01 Update PCB to v1.1 and document KiCad project files
    [230V.kicad_sch, BOM.csv, I2C.kicad_sch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]
2026-10-01 Add PCB v1.1 visualization to README
2026-10-01 Clarify KiCad project path variable in PCB README
2026-10-02 Simplify PCB documentation and describe repository directories
2026-10-02 Add filter test automation and trim README file descriptions
2026-11-08 Sync humidity sensors and Home Assistant recovery charts
2026-11-09 Expand ESPHome sensor and control documentation
